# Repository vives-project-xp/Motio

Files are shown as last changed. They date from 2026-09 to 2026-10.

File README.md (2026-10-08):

# Motio

*Makes motion visible.*





> Een innovatief project voor het zichtbaar en tastbaar maken van beweging,
> door meerdere bewegende elementen om te zetten in fysieke tekeningen op papier.

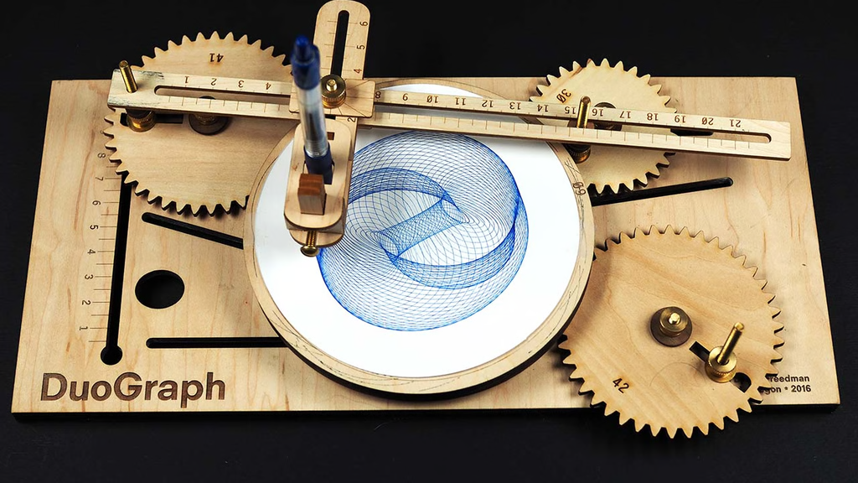
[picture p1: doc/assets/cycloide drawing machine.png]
cycloide drawing machine


## Inhoudsopgave

- [Motio](#motio)
  - [Inhoudsopgave](#inhoudsopgave)
  - [Projectoverzicht](#projectoverzicht)
  - [Functies](#functies)
  - [Technologie](#technologie)
    - [Hardware](#hardware)
    - [Software](#software)
  - [Project Structuur](#project-structuur)
  - [Simulators](#simulators)
    - [Beginposter](#beginposter)
  - [Team](#team)
  - [Academische Context](#academische-context)

## Projectoverzicht

Het Motio project is een initiatief ontwikkeld door 2de- en 3dejaars bachelorstudenten Elektronica-ICT van VIVES voor het vak Project Experience. Ons doel is het creëren van een systeem dat bewegingen tastbaar en zichtbaar maakt door ze om te zetten in fysieke tekeningen.

Het systeem combineert de beweging van meerdere elementen om complexe patronen te genereren. Een tekeninstrument vertaalt deze gecombineerde beweging naar lijnen op papier. Door parameters zoals snelheid, richting, fase en bewegingsverhouding te variëren, ontstaan telkens andere visuele patronen. Op die manier wordt de onderliggende beweging niet alleen geregistreerd, maar ook fysiek vastgelegd.

## Functies

- **Instelbare parameters:** snelheden, richtingen en fase zijn makkelijk regelbaar.
- **Visualisatie:** de beweging wordt gevisualiseerd door een tekeninstrument dat lijnen op papier maakt.
- **Preview:** indien mogelijk wordt de ingestelde beweging weergegeven op een scherm.
- **Modulaire opbouw:** gescheiden hardware- en softwarecomponenten voor eenvoudige uitbreiding.

## Technologie

### Hardware

- Stappenmotoren met dedicated drivers voor precisie-aansturing.
- Tekeninstrument als uitvoer naar papier.
- Raspberry Pi als besturingsplatform (zie [schermkeuzes](Research/Scherm/Scherm_gegevens.md) en [motor-aansturing](Research/Stappenmotoren/Stappenmotor_aansturing.md)).

### Software

- MOTIO SIMV4 in een zelfstandige map, met SIMV3 als behouden werkende basis.
- Parameterbesturing voor snelheid, richting, fase en bewegingsverhouding.

## Project Structuur

```bash
Motio/
├── doc/              # Projectdocumentatie en de projectcanvas
├── Hardware/         # Hardware van het project
├── Materiaal/        # Materiaallijst en benodigdheden
├── Research/         # Onderzoek en keuzes (scherm, stappenmotor-aansturing)
├── Software/         # Softwarecomponenten van het project
├── Software/WARD-SIM/ # Interactieve simulators
│   ├── SIMV1/        # Oorspronkelijke live simulator
│   ├── SIMV2/        # Virtueel prototype met machinebediening
│   ├── SIMV3/        # Behouden werkende basis met drie motoren, 2D/3D en BOM
│   └── SIMV4/        # Compacte box 358 × 404 × 108 mm en instelbare zichtbaarheid
└── README.md         # Dit bestand
```

## Simulators

- [SIMV1](Software/WARD-SIM/SIMV1/index.html): oorspronkelijke live simulator.
- [SIMV2](Software/WARD-SIM/SIMV2/index.html): virtueel prototype met machinebediening, mechanische transmissies en engineeringweergave. Zie de [SIMV2-handleiding](Software/WARD-SIM/SIMV2/README.md).
- [MOTIO SIMV3](Software/WARD-SIM/SIMV3/index.html): behouden werkende basis met rond papier Ø210 mm, veilige tekenzone Ø190 mm, drie SY42STH38-1684A-motoren en 2D/3D-interface. Zie [ontwerp en controles](Software/WARD-SIM/SIMV3/README.md).
- [MOTIO SIMV4](Software/WARD-SIM/SIMV4/index.html): huidige simulator met compacte opstelling, box 358 × 404 × 108 mm en afzonderlijke zichtbaarheid van wanden, bodem en bovenplaat. De drie motoren en bestaande bediening blijven behouden. Zie [starten en controles](Software/WARD-SIM/SIMV4/README.md).

### Beginposter

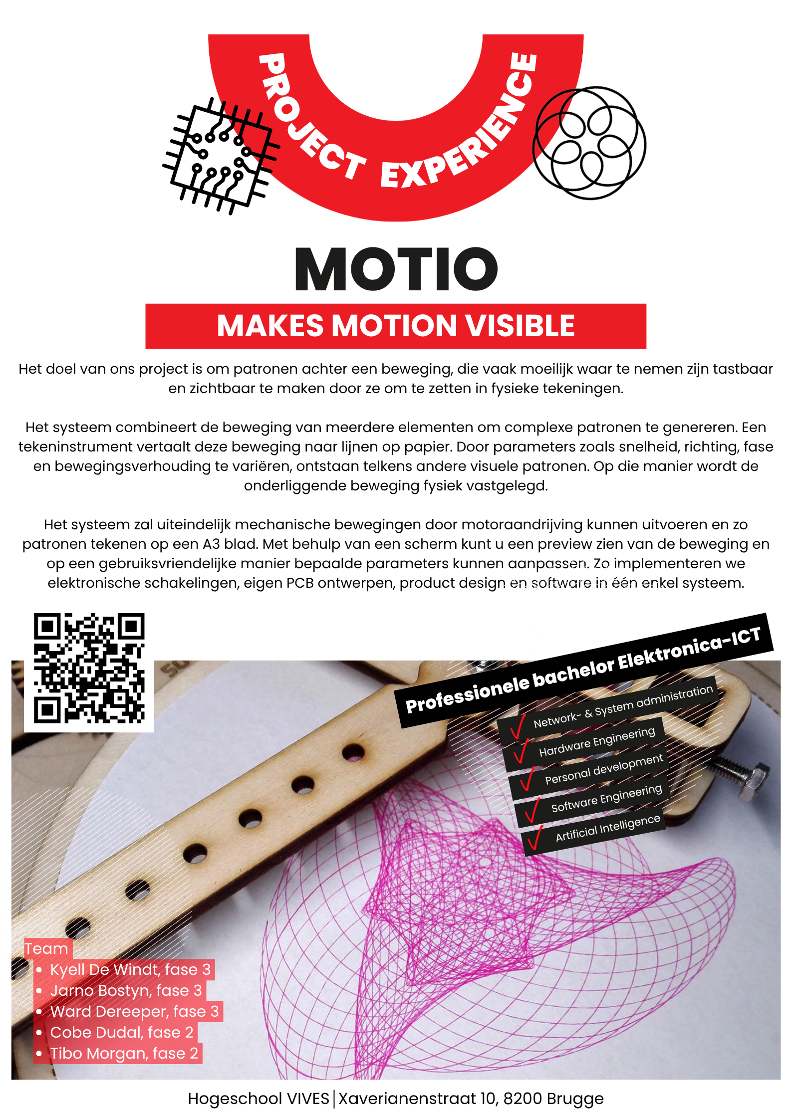
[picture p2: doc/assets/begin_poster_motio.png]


## Team

| | | |
| :---: | --- | --- |
| Kyell De Windt | Kyell De Windt | Teamlid |
| Jarno Bostyn  | Jarno Bostyn | Teamlid |
| Ward Dereeper | Ward Dereeper  | Teamlid |
|  Cobe Dudal  | Cobe Dudal | Teamlid |
| Tibo Morgan | Tibo Morgan | Teamlid |

## Academische Context

| | |
| --- | --- |
| Universiteit | VIVES Hogeschool |
| Opleiding | Bachelor Elektronica-ICT |
| Vak | Project Experience |
| Academiejaar | 2026-2027 |

Gemaakt door VIVES Bachelor Elektronica-ICT studenten.

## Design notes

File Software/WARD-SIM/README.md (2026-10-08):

# WARD-SIM

- [MOTIO SIMV4](SIMV4/index.html) - huidige simulator in een zelfstandige map: box 358 × 404 × 108 mm, compacte opstelling, drie onafhankelijke motoren en instelbare zichtbaarheid van de behuizing. Zie [starten en controles](SIMV4/README.md).
- [MOTIO SIMV3](SIMV3/index.html) - behouden werkende basis met rond papier Ø210 mm, drie motoren en 2D/3D-interface. Zie [ontwerp en controles](SIMV3/README.md).
- [Sim V1](SIMV1/index.html) - oorspronkelijke live simulator (historische referentie).
- [Sim V2](SIMV2/index.html) - eerder virtueel prototype (historische referentie).

Open de gewenste `index.html` in een browser; er is geen installatie nodig.

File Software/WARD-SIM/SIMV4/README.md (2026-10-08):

# MOTIO SIMV4

SIMV4 is een zelfstandige kopie van SIMV3 met een compactere opstelling en een houten box van **358 × 404 × 108 mm** (buitenafmetingen). Alle modelmaten blijven in millimeter. SIMV3 is intact gebleven.

## Starten

Open `index.html` rechtstreeks, of voer vanuit deze map uit:

```powershell
node tests/serve.js
```

Open [SIMV4 op deze computer](http://127.0.0.1:4174/). De server deelt alleen deze SIMV4-map. Er zijn geen externe bibliotheken of installatiecommando's nodig; voor de optionele server en tests is Node.js nodig.

## Bediening

De app opent in **Mechanical Design → 3D**. De vier afzonderlijke zijwanden en de bodem hebben elk een zichtbaarheidsschakelaar. De bovenplaat kan ondoorzichtig, semi-transparant of transparant worden weergegeven. Deze instellingen veranderen alleen de weergave; ze veranderen geen motorstand, beweging, tekening of machineconfiguratie.

De box en plaatsing volgen de meegeleverde visuele referentie. **A, B en C houden ieder een eigen motor en een eigen tandwielpaar.** Er zijn geen tandwielverbindingen tussen de drie aandrijvingen. A en B bedienen de twee penarmen; C draait het ronde papier. De draaipunten, armlengtes, motorbeugels en asdoorvoeren zijn aan de compactere box aangepast. De uiteinden van beide armen komen bij dezelfde penas samen.

De krukken blijven 65 mm; de penarmen zijn nu 180 / 160 mm. Het papier blijft Ø210 mm met een veilige tekenradius van 95 mm. De eigen tandwielparen liggen onder de bovenplaat en zijn zichtbaar te maken via de behuizingsbediening. De bovenplaat en bodem zijn 8 mm dik; de vier zijwanden zijn 8 mm dik. De hoogte van 108 mm is de buitenhoogte van de box, zonder het mechanisme erboven.

Alle bestaande SIMV3-bedieningen blijven beschikbaar: vier tabbladen, 2D/3D, camera draaien/verplaatsen/zoomen en boven-/zij-/isometrisch aanzicht, patronen en woordgenerator, afzonderlijke motorsnelheden/richtingen/fasen, configuratie, validatie en SVG-/CSV-export.

Om te tekenen: kies in **Simulator** een patroon, druk **Power on → Home → Play**. A/B bepalen de penpositie en C draait het papier. De penhoogte blijft handmatig vastgezet. **Pause** en **Stop** remmen af; **Play** hervat. **Reset → Home** begint opnieuw. Home zonder Reset kan een terugkeerlijn achterlaten. De snelheidsregelaar versnelt alleen de simulatietijd. Bij **Eigen motorinstellingen** zijn de drie motorsnelheden en richtingen afzonderlijk instelbaar.

Technische configuratiewijzigingen resetten de beweging en testgegevens. Configuratie staat centraal in `js/machineGeometry.js`; kinematica, controles, 2D/3D en BOM gebruiken dezelfde configuratie. Alleen de weergave schakelen laat de lopende simulatie ongemoeid.

## Controles en exports

Voer vanuit deze map uit:

```powershell
node tests/logic.test.js
node tests/integration.test.js
node tests/patterns.test.js
node tests/export.js
```

De regressiecontroles toetsen de FK/IK/Jacobiaan-berekeningen, onafhankelijke A/B/C-aandrijving, papiercoördinaten, bereik en vrijloop, motorlastmodel, foutstops en afremmen. De integratiecontrole gebruikt DOM/canvas-testdoubles voor de bestaande bediening, camera's en behuizingsschakelaars. De patroontest doorloopt alle bestaande patronen en letter-/woordgevallen op de live stapgrootte van 10 ms, inclusief pauzeren/hervatten. Echte WebGL en de zichtbare opstelling worden aanvullend in de browser bekeken.

`tests/export.js` genereert de mechanische SVG, doorsnede, pendetail en vijfkoloms BOM-CSV in `exports/`, met de SIMV4-configuratie.

De simulatie behoudt de bestaande geometrische veiligheidscontroles en geschatte motorbelasting. De afgelezen motorcurve bewijst het werkelijke gedrag bij lage RPM niet; drivercondities, belasting, spelingen en toleranties moeten op het fysieke prototype worden bevestigd. De tekeningen zijn een simulatie en geen productie-CAD.

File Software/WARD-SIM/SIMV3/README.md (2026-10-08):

# MOTIO V4 - mechanische simulator

V4 verfijnt de bestaande code in `SIMV3/`. De bestaande kinematica, WebGL-weergave en centrale configuratie blijven behouden. Geen installatie of externe runtimebibliotheken nodig.

Open `index.html` rechtstreeks, of start vanuit de repository:

```powershell
node Software/WARD-SIM/SIMV3/tests/serve.js
```

Open http://127.0.0.1:4173/SIMV3/.

## Bediening

Kies een patroon → Power on → Home → Play. De scrollbare lijst bevat dertien berekende voorbeeldafbeeldingen: cirkel, drie bloemen, golfring, twee eenvoudige rozetten, vier complexere verweven rozetten, spiraal en VIVES. Het volledige verwachte resultaat staat licht op het papier; de echte tekenlijn verschijnt donker en gebruikt onafhankelijk de bestaande voorwaartse kinematica. Voorbeeld tonen kan worden uitgeschakeld. A/B bepalen samen de penpositie; C draait het papier. Bij Eigen motorinstellingen gelden de invoersnelheden en richtingen voor de krukken en het papier. De live motorwaarden zijn de echte motoraswaarden: tegengesteld en vermenigvuldigd met de reductie. Positieve rotatie is met de klok mee in bovenaanzicht (+Y naar beneden).

De penhoogte wordt handmatig vastgezet. Home en afremmen tekenen ook. Pause/Stop remmen het ingestelde profiel af; een foutstop houdt de laatste toegestane pose vast. Dit is een virtuele interlock, geen garantie dat een echte machine instantaan kan stoppen. De geselecteerde patronen bewegen de pen over de al bewezen radiale route terwijl het papier draait. De twaalf geometrische figuren blijven binnen radius 81,7 mm; VIVES blijft binnen 82,7 mm en stoppen wanneer het volledige voorbeeld is getekend. De standaardbloem met vijf blaadjes duurt circa 36 simulatieseconden (circa 7 seconden bij 5×). Pause/Stop remmen op dezelfde curve af; Play hervat. Reset → Home begint een nieuwe tekening zonder het eerdere spoor. Home zonder Reset kan een terugkeerlijn achterlaten omdat de pen vast op het papier blijft. Willekeurige profielen hoeven niet volledig veilig te zijn: verboden standen worden geblokkeerd.

VIVES is een vaste lijntekening, geen algemene tekstgenerator. Afgeronde bubbelcontouren worden onderaan vloeiend verbonden met Catmull-Rom-curven, zonder de pen op te tillen of bij iedere knoop te stoppen. A/B blijven op de bewezen radiale route en C draait in beide richtingen: `r = hypot(x,y)` en `papierhoek = routehoek − atan2(y,x)`. De letterlijn ligt boven het papiercentrum zodat de papierhoek nergens onbepaald is. Het woord duurt circa 97 simulatieseconden bij 1×, circa 19 seconden bij 5×. Het profieltempo is 0,64 patroonrondes per minuut; de actuele A/B/C-snelheden variëren en worden door de bestaande limieten bewaakt.

1× gebruikt de werkelijke ingestelde bewegingssnelheid; de schuifregelaar versnelt alleen de simulatietijd. De geometrische patronen tekenen 1,5–4× sneller dan het vorige tempo: bloemen en de drie dichte rozetten 2×, golfring 1,5×, eenvoudige rozetten en de open rozet 3×, cirkel en spiraal 4×. De vier complexe figuren duren nu circa 7 min 33 s, 1 min 43 s, 6 min 43 s en 7 min 33 s bij 1×. Snelheids- en versnellingslimieten blijven ongewijzigd. De voorlopige uitgangslimieten zijn A/B 8 RPM en 1 rad/s², C 16 RPM en 3 rad/s². Bij VIVES op het nieuwe tempo geeft het model circa 8,8 / 4,8 / 51 motor-RPM als pieksnelheden en circa 0,06 Nm benodigd motorkoppel, met de huidige geometrie en belastingaannames. Dit zijn berekende startinstellingen voor een stroomgeregelde driver op 24 V en 1,68 A, geen gemeten maximale machinesnelheid. De drivercondities blijven onbevestigd totdat de echte opstelling is gecontroleerd.

Precies vier tabbladen: Simulator, Mechanical Design, Validation en Components / BOM. Technische instellingen zijn uitgeklapt beschikbaar. Configuratiewijzigingen resetten de beweging, tekening en testgegevens.

### Woordgenerator

Typ 1 tot 8 letters (A–Z) in de woordgenerator. Kleine letters worden hoofdletters; spaties, cijfers en leestekens worden niet geaccepteerd. Het voorbeeld reageert tijdens het typen. **Gebruik woord** zet het woord op het papier en vraagt opnieuw Home; daarna werkt de bestaande bediening. Het woord wordt bewaard als `wordText` in de centrale configuratie en kan dus mee worden geëxporteerd.

De generator gebruikt een klein ingebouwd alfabet met afgeronde contouren, smalle I en bredere M/W. Letterverhoudingen blijven behouden; de grootte en tussenruimte worden automatisch bepaald. De volledige curve blijft binnen 86% van de veilige radius. De tekst wordt horizontaal gecentreerd en boven het papiercentrum geplaatst, zodat de bestaande radiale penroute en papierrotatie kunnen worden hergebruikt. De letters en binnenlussen vormen één pad met de pen op het papier. De tekentijd volgt het aantal curvegedeelten, zodat langere woorden meer tijd krijgen. Het gevraagde woordtempo is 0,9 patroonrondes per minuut. Bij het toepassen wordt het volledige woordpad op 64 stappen per curvegedeelte doorgerekend en het tempo zo nodig verlaagd voor de bestaande pen- en motorlimieten, met 30% reserve in de berekende constante beweging. Korte woorden kunnen daardoor een lager tempo krijgen; een hogere vaste snelheid zou daar een foutstop veroorzaken. Er zijn geen externe lettertypen of extra bibliotheken nodig.

## Bouwgeometrie

| Onderdeel | Keuze |
|---|---|
| Papier en draaiplateau | Rond Ø210 mm, gecentreerd |
| Veiligheidsmarge | 10 mm; tekenradius 95 mm / diameter 190 mm |
| Krukken A/B | 65 mm h.o.h. (voorheen 40 mm) |
| Penarmen A/B | Bestaande 360 / 340 mm h.o.h. |
| Draaipunten A/B | Bestaande (550,148.5) / (210,-185) mm |
| A/B tandwielparen | 20:60 tanden; module 1,5; hartafstand 60 mm; 3:1 |
| C tandwielpaar | 20:80 tanden; module 1,5; hartafstand 75 mm; 4:1 |
| Tandprofiel | Rechte tanden, 20° drukhoek, breedte 9 mm |
| Pen | Holle joint, twee onafhankelijke armlagers, manuele M4-klem |
| Onderplaat | 605 × 605 × 8 mm; frame en steunen passen binnen dezelfde plaat |

Eén motor- en één uitgangstandwiel per aandrijving. Uitwendige tandwielen draaien tegengesteld. De involute visualisatie gebruikt bijpassende tooth/gap-fases in 2D en 3D; het profiel is geen productie-CAD. De berekende theoretische contactratio is circa 1,67 voor A/B en 1,69 voor C. Naaf, materiaal, passingen en werkelijke tandspeling nog kiezen vóór fabricage.

## Bereik en veiligheid

De pen hoeft niet alle XY-punten zelfstandig te bereiken. Een continue radiale machinepositie `P(s) = papiercentrum + s·(cos(-140°),sin(-140°))`, voor `0 ≤ s ≤ 95 mm`, bestrijkt met onafhankelijke papierrotatie iedere radius en papierhoek.

`validation.js` controleert deze route over 190 aaneengesloten intervallen van 0,5 mm. Het gebruikt exacte afstandsgrenzen tot de draaipunten, de crank/arm-driehoek voor seriële singulariteiten, begrensde elleboogverplaatsingen voor parallelle sluiting en verplaatsingsenveloppen voor vrijloop. Dit zijn intervalgrenzen voor de volledige route, geen PASS op basis van losse steekproeven.

Voor de standaardconfiguratie: seriële sinusmarge minstens 0,410; parallelle sinusmarge minstens 0,991; Jacobiaanconditie hoogstens 2,79; gemodelleerde vrijloop minstens 4,22 mm (eis 3 mm). Volledige veilige tekencirkel: PASS in dit geometrische model. Botsingen en singulariteiten: PASS op deze route, met die reikwijdte expliciet in de interface. De fysische motorcapaciteit en spelingen: NIET BEWEZEN.

De bestaande faserastertest en 20 s omkeerproef blijven op de achtergrond beschikbaar. Een raster bewijst geen globale veiligheid. De simulator weigert kritische singulariteiten, botsingen, assembly/working-branchwissels en een penpositie buiten radius 95 mm. Tekensporen staan uitsluitend in roterende papiercoördinaten; papier en spoor draaien samen in alle weergaven.

## Motorbron en berekeningen

Bron: [meegeleverde SY42STH38-1684A-datasheet](../../../Research/Datasheets/Stappenmotoren/SY42STH38-1684A.pdf).

Drie identieke motoren: 1,8° (200 volle stappen/omwenteling), 1,68 A, 2,8 V per fase, houdkoppel 0,36 Nm, as Ø5 mm, motorbreedte maximaal 42,3 mm, lengte 38 ±1 mm en vier M3-gaten op 31 ±0,2 mm. De motor wordt met een stroomgeregelde driver gevoed; 2,8 V is de nominale fasespanning, de curve gebruikt een voeding van 24 V.

De pull-out-curve is ongeveer afgelezen uit de PDF. Condities: 24 VDC, constante stroom 1,68 A, halfstap. De x-as is PPS, niet RPM: 400 pulsen/omwenteling geeft `RPM = PPS × 60 / 400`. Het getoonde curvebereik 200–5000 PPS is 30–750 RPM. Afgelezen dynamisch koppel circa 0,26 Nm bij 30 RPM, oplopend naar circa 0,30 Nm bij 105 RPM en aflopend naar circa 0,19 Nm bij 750 RPM. Er wordt geen curve buiten dit bereik geëxtrapoleerd en geen houdkoppel als dynamisch koppel gebruikt.

Bij de patroonprofielen wisselen A/B van snelheid en richting; C draait bij de standaardbloem op maximaal 7,2 motor-RPM. De lage motorsnelheden liggen buiten het gepubliceerde curvebereik. Daarom blijft dynamische capaciteit daar niet aangetoond. Bij VIVES bereikt C circa 51 motor-RPM, binnen het curvebereik, maar ook dit patroon passeert lagere snelheden en stilstand. Ook binnen het curvebereik moet de gebruiker drivercondities bevestigen (`motorCurveConditionsConfirmed`) voordat een curvevergelijking als onderbouwd geldt. Een eigen gemeten curve kan via het bestaande `motorCurves`-veld, met bron, oplopende `[RPM,Nm]`-punten en `conditionsConfirmed:true`, worden ingevoerd. Werkelijke belastingmetingen blijven nodig.

Volle motorstappen per uitgangsomwenteling: A/B 600, C 800. In halfstap zijn dit 1200 / 1600 pulsen. Het bestaande gekoppelde lastmodel gebruikt penlast, arm-/krukmassa, inertie, wrijving, versnelling en rendement; het is een schatting. Aangenomen: penwrijving 2 N, pendruk 2 N, aluminium E=69000 N/mm²/dichtheid 2700 kg/m³, efficiëntie 85%, draaiende massa 0,45 kg en geschatte rotor-/tandwielinertie. Alleen de Ø210×4 mm aluminiumplaat weegt circa 0,374 kg; 0,45 kg omvat een voorlopige flens-/papierbijdrage. Deze aannames komen niet uit de motorcurve.

## Centrale bestanden en controles

`machineGeometry.js` bevat de centrale configuratie en gedeelde constructievolumes. Kinematica, papiertransformatie, collision checking, motorberekeningen, 2D/3D, Validation en BOM gebruiken dezelfde configuratiesnapshot. `motorAnalysis.js` bevat alleen de afgelezen broncurve, met het bestaande configuratieveld voor eigen curves. `patterns.js` bevat acht eenvoudige figuren, vier complexere verweven rozetten en één vaste letterlijn met hun voorbeelden; het geselecteerde `patternId` staat in dezelfde centrale configuratie. De beginhoeken worden uit inverse kinematica bepaald. De bestaande simulator berekent de daadwerkelijke penpositie, snelheid, versnelling en veiligheidscontroles.

```powershell
node Software/WARD-SIM/SIMV3/tests/logic.test.js
node Software/WARD-SIM/SIMV3/tests/integration.test.js
node Software/WARD-SIM/SIMV3/tests/patterns.test.js
node Software/WARD-SIM/SIMV3/tests/export.js
```

De tests controleren 5184 FK/IK/Jacobiaanstanden, tandwielhartafstanden en rotatierichting, ronde grenzen, het continue bereikbewijs en onafhankelijke papiercoördinaten, collision-fixtures, lastmodel, motorcurvecondities, handmatige penhoogte, behoud van de laatste geldige pose, afremmen, centrale configuratiedoorwerking, vier tabs, vijf controles en vijfkoloms CSV. De patroontest voert alle dertien profielen en 33 letter-/woordgevallen volledig uit op de live stapgrootte van 10 ms. Hij controleert pauzeren/hervatten, volledige voltooiing zonder foutstop, reserves in motor-RPM en versnelling, minstens factor 2 koppelreserve waar de gepubliceerde curve geldig is, de overeenkomst tussen FK en het onafhankelijke voorbeeld, de veilige grens en de compactere plaat. Koppel buiten het gepubliceerde RPM-bereik blijft niet aangetoond; drivercondities en werkelijke belasting moeten op de machine worden bevestigd. DOM/canvas-testdoubles worden aangevuld met visuele browsercontrole van echte WebGL en de interface.

`exports/` bevat V4-SVG-tekeningen en de vijfkoloms BOM-CSV. Sim V1/V2 blijven historische versies.

Nog te bevestigen aan het prototype: driver/voeding, motorlast bij lage RPM, tandflankspeling, lager-/aspassingen, toleranties, papierloop, schroef- en naafdetails. Het envelopmodel bevat niet alle bevestigingskoppen en kabels. Het geometrische bereikbewijs is geen fysieke bouwvrijgave.

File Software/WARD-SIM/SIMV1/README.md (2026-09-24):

# MOTIO Live Simulator V1

Een lokale, dependency-vrije browserapp die de gekoppelde beweging van één driver, een roterend A3-blad en twee extern gemonteerde tekenarmen live simuleert.

## Starten

Open `index.html` rechtstreeks in een recente versie van Chrome, Edge of Firefox. Er is geen installatie, build-stap of backend nodig.

## V1-mechanisme

**ASSUMPTION V1:** de driver stuurt drie onafhankelijke uitgangen aan. De eerste roteert het A3-papier rond zijn centrum. Arm A wordt door een excentrische kruk rechts buiten het blad aangedreven; Arm B door een tweede excentrische kruk boven het blad. Beide stijve armen ontmoeten elkaar in één penwagen. De penpositie wordt exact berekend als het geometrische snijpunt van twee cirkels rond de actuele krukpennen. Geen enkel draaipunt of geleiding is aan het papier bevestigd.

Voor een direct tandwielpaar geldt `ratio = -driver_teeth / output_teeth`. De pen wordt eerst in wereldcoördinaten berekend. Daarna wordt de inverse papierrotatie toegepast en wordt het spoor in lokale A3-coördinaten opgeslagen. Daardoor draait het getekende spoor in Machine View correct mee met het papier en blijft het in Paper View vast staan.

## Aanbevolen eerste test

1. Gebruik `Dual arm test · 20 / 60 / 37 / 53`.
2. Klik **Play** en bekijk beide views.
3. Klik **Pause**.
4. Wijzig Arm A teeth van `37` naar `41` (de simulatie reset automatisch).
5. Klik **Play** en vergelijk het nieuwe patroon en de exacte repeat-periode.

## Bestanden

- `index.html` — interface en semantische structuur
- `style.css` — responsieve technische vormgeving
- `js/math.js` — breuken, GGD/KGV en coördinatentransformaties
- `js/simulation.js` — tandwielen, tijdstap, kinematica en trace
- `js/renderers.js` — Machine View en Paper View
- `js/ui.js` — controls en live datapanel
- `js/app.js` — vaste simulation timestep en renderloop
- `tests/logic.test.js` — automatische tests voor ratios, transformaties en live trace

De scripts worden bewust als gewone lokale scripts geladen (niet als ES-modules), zodat de app ook via een `file:///`-adres werkt en geen lokale webserver vereist.

Optioneel kan de logica worden gecontroleerd met `node tests/logic.test.js`.

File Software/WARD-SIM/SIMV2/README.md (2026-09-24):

# MOTIO — SIMV2

Virtueel prototype, doorontwikkeld uit SIMV1. Open `index.html` rechtstreeks in een browser; geen installatie nodig.

## Bediening

1. **Power on → Home**. De gekoppelde assen keren in een geïdealiseerde referentieroutine terug naar nul. De ingestelde krukfasen blijven behouden.
2. **Pen down → Play**. Machine View toont de machine; Paper View toont het vaste A3-papierbeeld.
3. **Pause** behoudt de positie. **Stop** stopt op de actuele positie en heft de pen. **Reset** wist het spoor, reset de simulatie en vereist opnieuw Home.
4. Gear-, fase-, geometrie- en richtingswijzigingen resetten de tekening en vereisen Home. Simulation speed verandert alleen de afspeelsnelheid.
5. Engineering overlay toont steekcirkels, krukbanen, toerentallen, coördinaten en referentiekaders.

## ASSUMPTION FOR V1 — mechanische architectuur

Eén motor drijft een centrale as met drie gelijke tandriempoelies. Drie afzonderlijke 1:1 riemtrappen op verschillende hoogtes koppelen die as aan gelijke driver-pinions. Elke pinion grijpt in een verwisselbaar uitgaand tandwiel: papier, Arm A of Arm B. Alle assen staan in lagerblokken; de pinionposities verschuiven met de tandenaantallen. Riemlengtes en spanning moeten na wisselen mechanisch worden aangepast.

Module 1 mm: steekstraal = tanden / 2 mm; hartafstand = (driver + uitgang) / 2 mm. De getekende tanden zijn schematisch, geen productieklare involuutprofielen. Het papierwiel zit coaxiaal onder het platform; een gelabelde doorsnede toont dit verborgen tandwielpaar. Stippellijnen zijn onderliggende riemtrajecten, geen losse actuatoren. De krukken zitten op de uitgaande assen boven de transmissies. Armen liggen in verschillende hoogtevlakken en ontmoeten elkaar in een gemeenschappelijke penhouder.

Een rond platform Ø526 mm draagt een gecentreerd A3-blad van 420 × 297 mm. Het spoor is opgeslagen in papiercoördinaten en draait in Machine View mee met het blad. De Paper View behoudt de lokale coördinaten. De marge is 20 mm. Buiten het blad of met geheven pen ontstaat geen spoor; bij hervatting begint een nieuwe lijn.

## Berekening

Driverhoek → verhouding −driverT/outputT → krukpennen → snijpunt van twee cirkels met vaste armlengtes → wereldpositie pen → inverse papierrotatie → tekening.

SIMV1's bestaande cirkelsnijpuntmodel, panelen, presets en vaste tijdstap zijn behouden. De continuïteitskeuze gebruikt nu afstand tot de vorige penpositie, zonder voorkeur die plots van tak wisselt om binnen het papier te blijven. Onbereikbare geometrie blokkeert de aandrijving.

De exacte gezamenlijke faseherhaling is het KGV van de gereduceerde ratio-noemers in driveromwentelingen. Een symmetrisch patroon kan eerder visueel herhalen. De weergegeven duur gebruikt driver-RPM, zonder versnellingsrampen. RPM verandert tijdsverloop, niet de geometrische patroonvorm; tandenaantallen, fasen, krukstralen en armlengtes veranderen die wel. Omkeren keert de doorlooprichting om.

## Scope en bron

Gebaseerd op de meegegeven masterprompt en de projectbeschrijving in de repository-README. Er was geen afzonderlijke projectbrief beschikbaar. Mechanische opbouw, module, platformdiameter, controller en sensoren zijn expliciete prototypeaannames.

Dit is ideale kinematica: geen berekening van motorvermogen, buiging, backlash, riemspanning, botsingen of toleranties. De homingroutine interpoleert de gemeenschappelijke driverfase in twee simulatieseconden naar de virtuele referentie; dit is geen firmware of realistisch begrensd motorprofiel. Sensorblokjes zijn statusindicatoren. Voor een bouwontwerp zijn hoogteverschillen, vrije ruimte en montage nog te controleren. Het spoor bewaart maximaal circa 350.000 punten en verwijdert daarna de oudste 50.000 om geheugen te begrenzen.

## Controle

`node tests/logic.test.js`

Controleert ratios, transformaties, vaste armlengtes, continuïteit, machine-interlocks, homing, penonderbrekingen, veranderde tandenaantallen, richting, faseherhaling en RPM-tijdschaling.

`node tests/integration.test.js`

Controleert de bestaande HTML-controls en rendercode met een gesimuleerd document en canvas, inclusief tekenen, onderbreken en hervatten. Dit vervangt geen visuele browsercontrole. De ingebouwde browser blokkeerde het lokale file-adres tijdens ontwikkeling, dus visuele QA is niet afgerond.

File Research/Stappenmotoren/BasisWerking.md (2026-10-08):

# Basis werking

## Wat is een stappenmotor
Een stappenmotor is een borstelloze synchrone gelijkstroommotor die digitale pulsen omzet in rotatie van een mechanische as.In tegenstelling tot veel andere standaardtypen motoren, draait een stappenmotor niet continu gedurende een bepaald aantal omwentelingen totdat de gelijkspanning die eraan wordt geleverd, wordt uitgeschakeld. Het heeft verschillende spoelen die in groepen zijn georganiseerd, de zogenaamde "fasen". Als elke fase beurtelings wordt ingeschakeld, draait de motor stap voor stap.

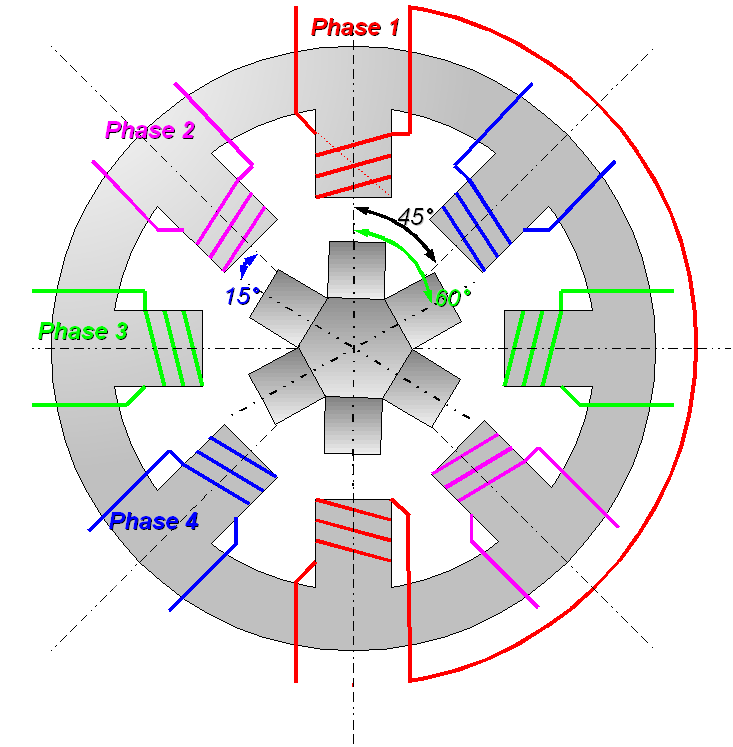
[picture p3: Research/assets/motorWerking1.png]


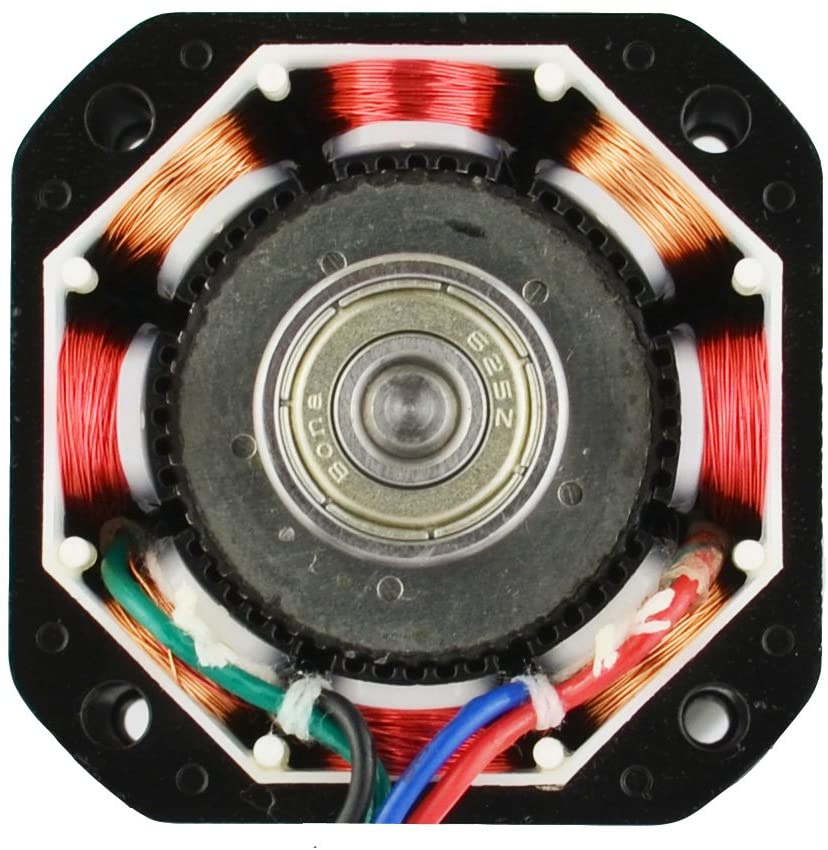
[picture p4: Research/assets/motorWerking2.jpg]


Stappenmotoren verdelen de gehele draaibeweging in meerdere gelijke stappen. Zolang de motor de juiste afmetingen heeft voor het koppel en de snelheid van de toepassing, kan de positie van de motor worden geregeld om in een van deze stappen te bewegen en daar te blijven zonder enige feedback van een positiesensor.

Bronnen:
(https://www.stepperonline.nl/stappenmotoren)
https://nl.wikipedia.org/wiki/Stappenmotor

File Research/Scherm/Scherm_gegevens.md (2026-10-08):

## Scherm
Eventuele keuzes voor het scherm bedoelt voor een Raspberry Pi:

Optie 1: https://www.kiwi-electronics.com/en/raspberry-pi-touch-display-2-7-inch-20235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

Optie 2: https://www.amazon.com/dp/B0D3QB7X4Z?tag=nerdtechy-20&th=1

Optie 3: https://eu.robotshop.com/products/7-in-capacitive-touch-screen-1024x600-hdmi

Optie 4: https://www.raspberrystore.nl/PrestaShop/nl/beeldschermen/612-raspberry-pi-touch-display-2-5056561803937.html

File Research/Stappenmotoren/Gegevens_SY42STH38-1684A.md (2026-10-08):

# Technische gegevens

## SY42STH38-1684A

Step angle: 1,8
Number of phase: 2
Rated Voltage (V): 2,8
Rated Current (A): 1,68
Resistance Per Phase (Ohm): 1,65

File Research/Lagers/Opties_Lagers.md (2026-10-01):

# Lagers
Mogelijke opties voor lagers om te bestellen.

Optie 1: https://kogelrollen.be/kogelrol-kogelpot-15875-mm-met-bevestigingsgaten/80041200-p-41200.html

Optie 2: https://www.neita.nl/webshop/lagers/overige-lagers/sps-15-b-kogelpot-15mm-300193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

Mochten de andere opties niet van toepassing zijn: https://www.amazon.com.be/-/nl/Kogellager-Draaibare-Bearing-Vierkante-Computer/dp/B099R5PK89?language=nl_BE

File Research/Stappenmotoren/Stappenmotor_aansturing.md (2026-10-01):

## Stappenmotor
Eventuele driver voor stappenmotoren: https://www.poscope.com/product/bipolar-stepper-motor-driver-postep25-256/

We hebben 2 drivers nodig.

Gegevens van motor ST42STH38-1684A: https://www.pololu.com/product/2267/pictures
Gegevens van motor Stepping Motor 42BYG-40015-22BA: https

Aansluitkabels voor stappenmotors:
https://be.farnell.com/en-BE/multicomp-pro/mp008749/cable-assy-6p-rcpt-free-end-150mm/dp/3886084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

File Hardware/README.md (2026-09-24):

# Hardware

In dit document zal alles te maken met de hardware van dit project terug te vinden zijn..

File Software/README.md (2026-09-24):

# Software

In deze map zal alles te maken met de software terug te vinden zijn.

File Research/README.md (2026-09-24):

# Research
In deze map zal het gemaakte onderzoek in verband met dit project terug te vinden zijn.

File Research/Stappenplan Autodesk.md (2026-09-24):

We werken met Fusion 360,
voor een tandwiel te tekenen in fusion 360 zit dit standaard ingebouwd zodat je de nodige waarden moet ingeven van je tandwiel en die word dan gemaakt. 
Je kan dit doen aan de hand van de mode SpurGear (we moeten deze nog aanzetten).

Hoe zet ik SpurGear aan?

1. je maakt een nieuwe part design.
2. je gaat naar utilities Utilities
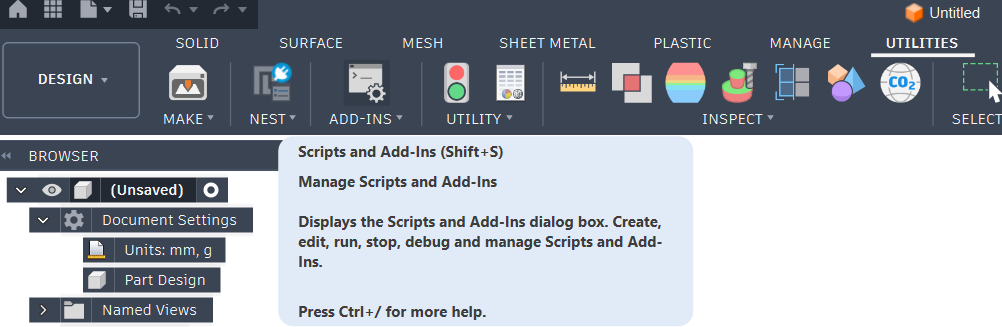
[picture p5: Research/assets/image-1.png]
ADD-INS
3. nu klik je op "ADD-INS" 
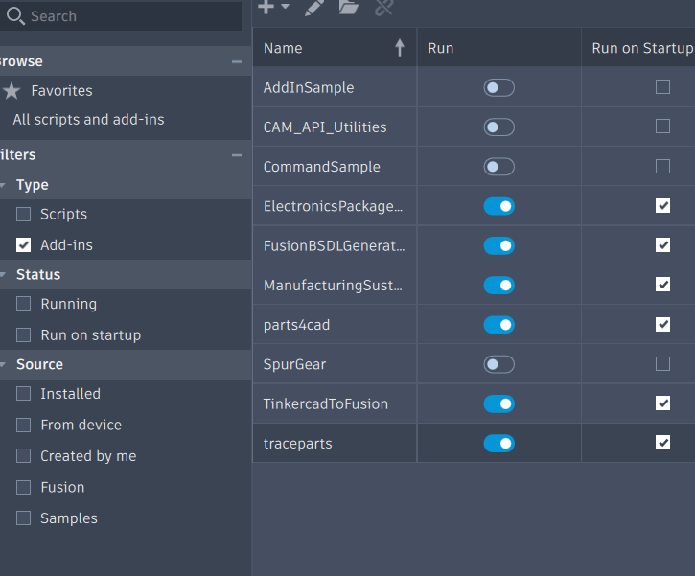
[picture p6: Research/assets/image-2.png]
SpurGear
4. nu moet je de ADD-IN  "SpurGear" aanzetten en aanvinken. 
5. Nu gaan we terug naar "Solid" Solid
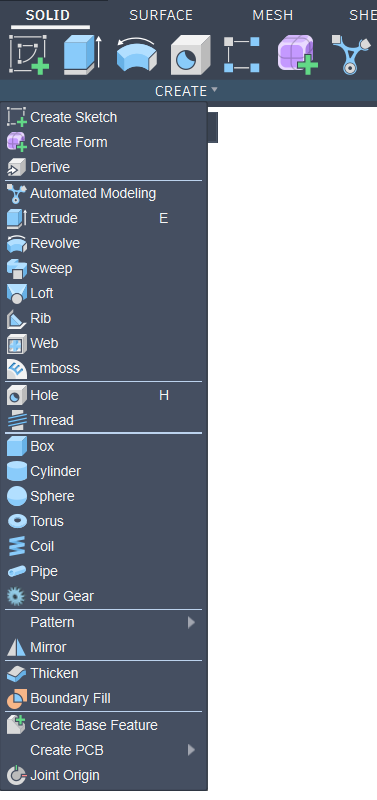
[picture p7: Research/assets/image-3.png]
Create Spurgear
6. We klikken dan op "CREATE" en dan op Spur Gear 
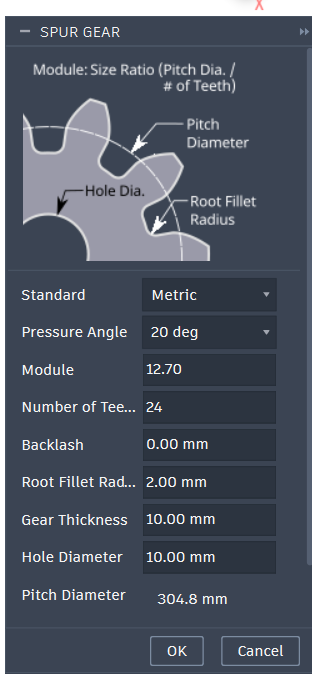
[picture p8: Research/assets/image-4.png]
Tandwiel settings
7. Je krijgt dan een venster met de nodige info die we moeten aanpassen voor een juiste tandwiel te krijgen. Hier moeten we onze eigen waarden invullen voor de nodige tandwiel. 
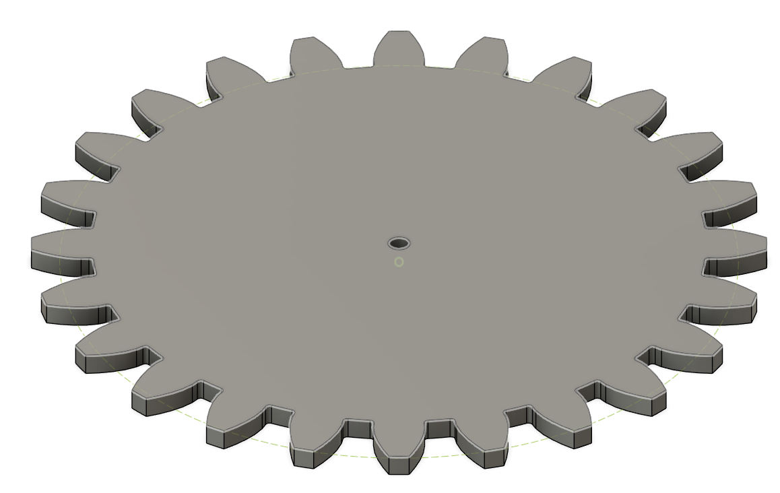
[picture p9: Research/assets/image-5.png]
resultaat tandwiel
8. Als je dan waarden hebt ingegeven dan krijd je het volgende als resultaat:

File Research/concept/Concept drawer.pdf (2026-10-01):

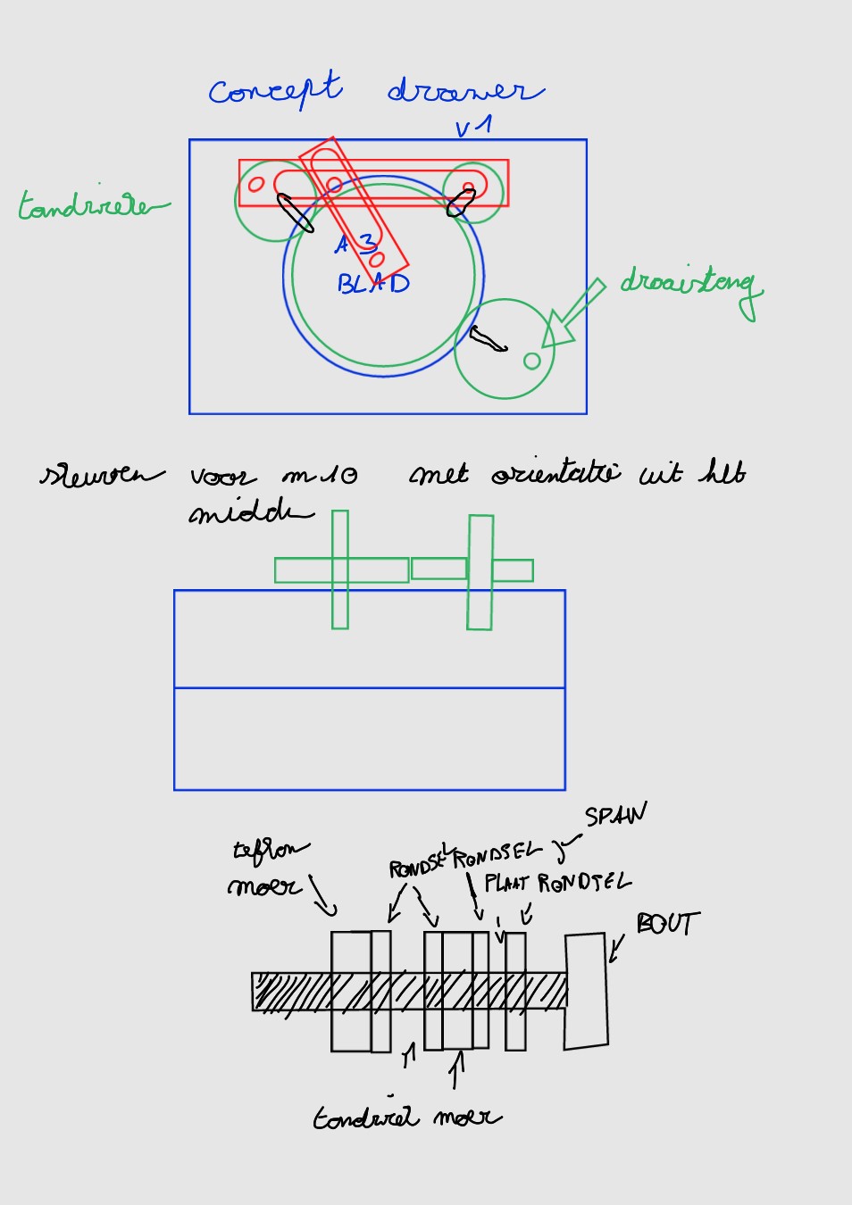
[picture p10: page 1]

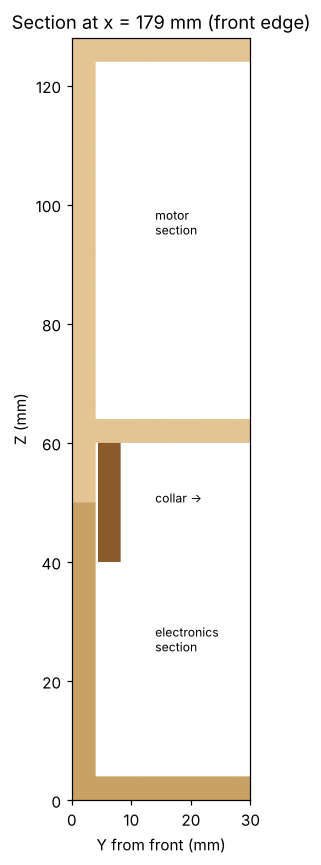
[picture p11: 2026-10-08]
Research/concept/v2/lasersnij/doorsnede_rand.png

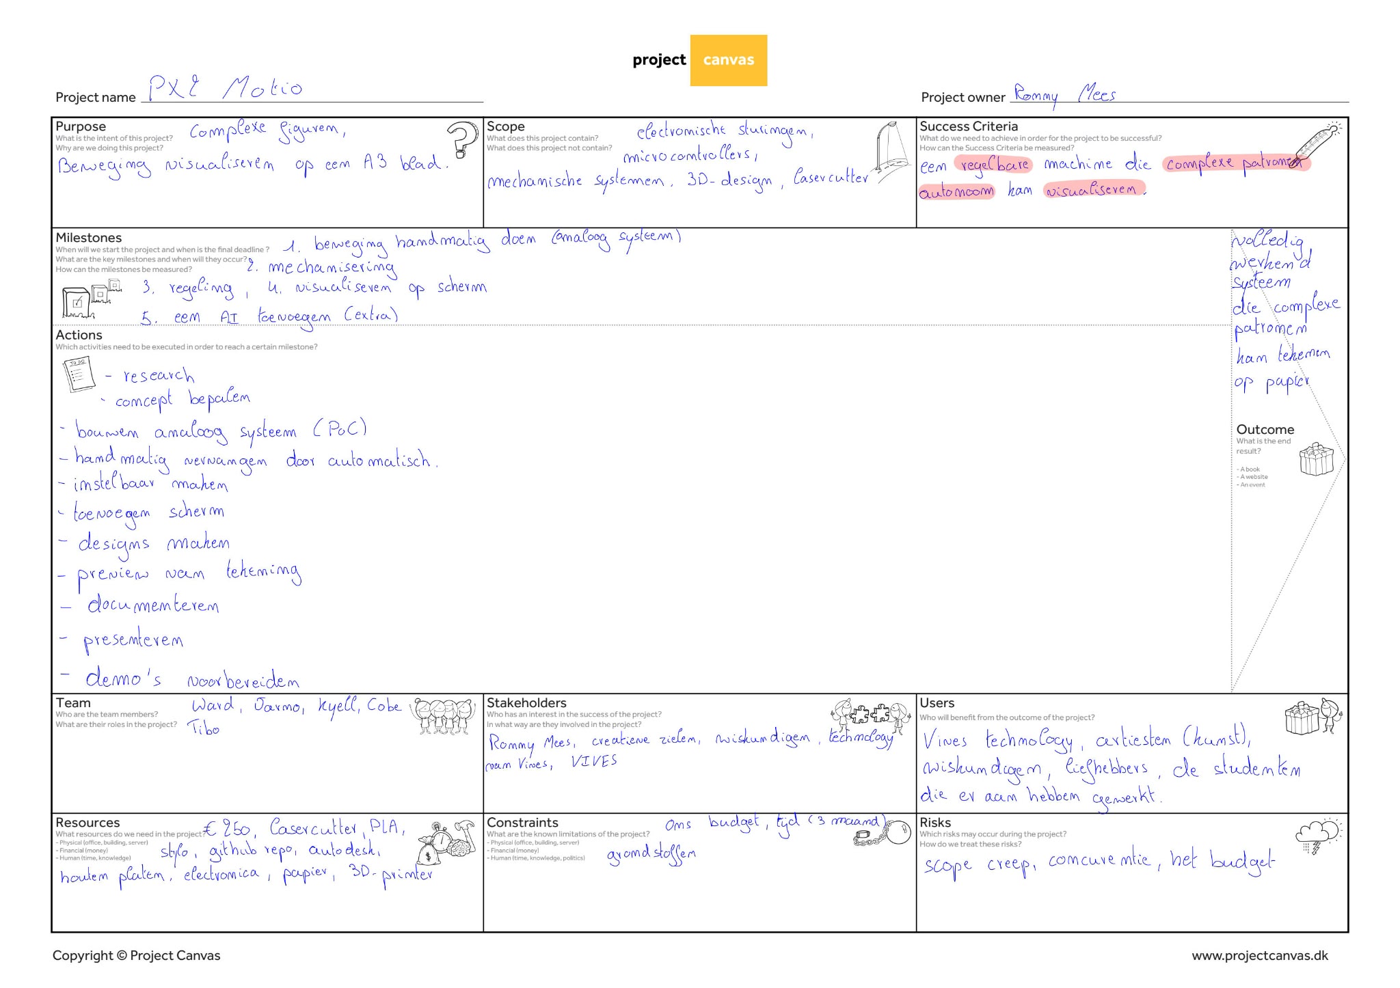
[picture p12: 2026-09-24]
doc/assets/project canvas motio.jpeg

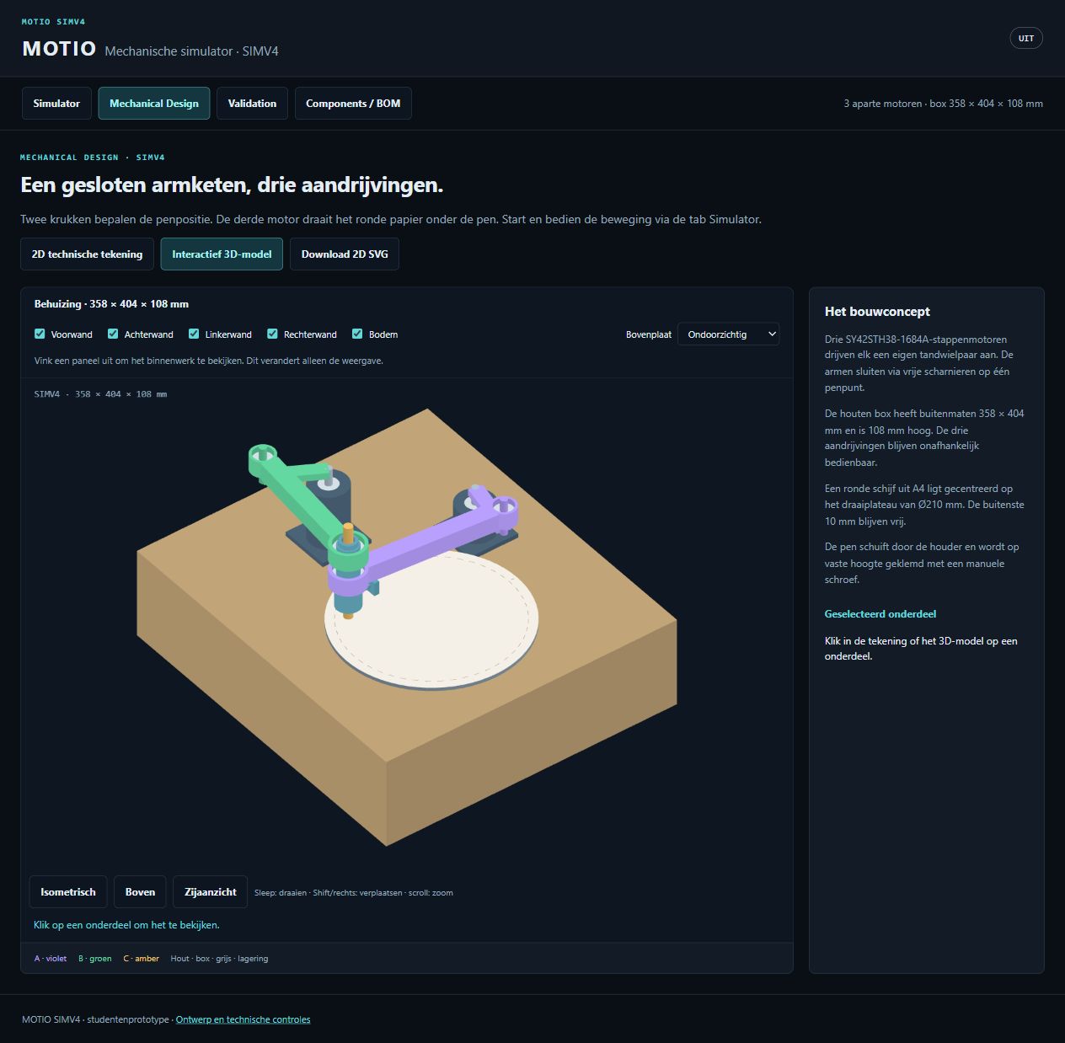
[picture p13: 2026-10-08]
Software/WARD-SIM/SIMV4/exports/SIMV4-preview.png

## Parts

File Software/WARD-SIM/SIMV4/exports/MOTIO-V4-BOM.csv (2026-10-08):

Onderdeel | Aantal | Afmetingen | Materiaal | Specificatie / opmerking
Stappenmotor A · SY42STH38-1684A | 1 | 42.3 × 42.3 × 38 mm; as Ø5 mm | Staal / koper | 1.8°; 1.68 A; 2.8 V per fase; houdkoppel 0.36 Nm. 4 × M3 op 31 mm. Dynamisch koppel: datasheetcurve bij 24 V / 1,68 A / halfstap.
Aandrijfas A | 1 | Ø8 × 98 mm | Staal | Schouderas met borging; lagerpassingen nog vastleggen.
Lagersteun A | 1 | Ø44 mm; lagerafstand 32 mm | Aluminium | Eén lager lokaliseert axiaal; tweede buitenring kan axiaal schuiven.
Uitgangstandwiel A | 1 | 60 tanden; module 1.5; steek Ø90 × 9 mm; boring Ø8 | Nog kiezen | Rechte tanden, 20° drukhoek; reductie 3:1; hartafstand 60 mm. Motor en uitgang draaien tegengesteld. Naaf en materiaal vóór bouw kiezen.
Kruk A | 1 | 65 mm h.o.h. × 16 × 8 mm | Aluminium | Klemnaaf Ø8; elleboogscharnier Ø8.
Penarm A | 1 | 180 mm h.o.h.; koker 20 × 20 × 1.5 mm | Aluminium | Met eindstukken en vrije scharnieren; armlaag z84 mm.
Stappenmotor B · SY42STH38-1684A | 1 | 42.3 × 42.3 × 38 mm; as Ø5 mm | Staal / koper | 1.8°; 1.68 A; 2.8 V per fase; houdkoppel 0.36 Nm. 4 × M3 op 31 mm. Dynamisch koppel: datasheetcurve bij 24 V / 1,68 A / halfstap.
Aandrijfas B | 1 | Ø8 × 130 mm | Staal | Schouderas met borging; lagerpassingen nog vastleggen.
Lagersteun B | 1 | Ø44 mm; lagerafstand 32 mm | Aluminium | Eén lager lokaliseert axiaal; tweede buitenring kan axiaal schuiven.
Uitgangstandwiel B | 1 | 60 tanden; module 1.5; steek Ø90 × 9 mm; boring Ø8 | Nog kiezen | Rechte tanden, 20° drukhoek; reductie 3:1; hartafstand 60 mm. Motor en uitgang draaien tegengesteld. Naaf en materiaal vóór bouw kiezen.
Kruk B | 1 | 65 mm h.o.h. × 16 × 8 mm | Aluminium | Klemnaaf Ø8; elleboogscharnier Ø8.
Penarm B | 1 | 160 mm h.o.h.; koker 20 × 20 × 1.5 mm | Aluminium | Met eindstukken en vrije scharnieren; armlaag z116 mm.
Stappenmotor C · SY42STH38-1684A | 1 | 42.3 × 42.3 × 38 mm; as Ø5 mm | Staal / koper | 1.8°; 1.68 A; 2.8 V per fase; houdkoppel 0.36 Nm. 4 × M3 op 31 mm. Dynamisch koppel: datasheetcurve bij 24 V / 1,68 A / halfstap.
Aandrijfas C | 1 | Ø12 × 95 mm | Staal | Schouderas met borging; lagerpassingen nog vastleggen.
Lagersteun C | 1 | Ø42 mm; lagerafstand 44 mm | Aluminium | Eén lager lokaliseert axiaal; tweede buitenring kan axiaal schuiven.
Uitgangstandwiel C | 1 | 80 tanden; module 1.5; steek Ø120 × 9 mm; boring Ø12 | Nog kiezen | Rechte tanden, 20° drukhoek; reductie 4:1; hartafstand 75 mm. Motor en uitgang draaien tegengesteld. Naaf en materiaal vóór bouw kiezen.
Motortandwiel | 3 | 20 tanden; module 1.5; steek Ø30 × 9 mm; boring Ø5 | Nog kiezen | Rechte tanden, 20° drukhoek; klemnaaf voor motoras.
Motorbeugel | 3 | 54 × 54 × 5 mm; 4 × M3 op 31 mm | Aluminium | Vaste bevestiging met beperkte uitlijnmogelijkheid voor tandspeling.
Groefkogellager 608-2RS | 6 | 8 × 22 × 7 mm | Lagerstaal | Vier hoofdlagers en twee ellebooglagers.
Penlager 6804 | 2 | 20 × 32 × 7 mm | Lagerstaal | Onafhankelijke armrotatie rond de holle penas. Uitvoering en passing nog kiezen.
Plateaulager 6001 | 2 | 12 × 28 × 8 mm | Lagerstaal | Twee gescheiden lagerposities op de papierspindel.
Elleboogscharnier | 2 | Schouderpost Ø8 mm; M6 borging | Staal | Schroefdraad buiten het draaiende lagervlak.
Holle penas | 1 | Ø20; boring Ø13 mm | Staal | Pen loopt door beide armlagers. Schouders en borgmoer nog detailleren.
Afstandbus en axiale borging | 1 | Ø24/20; afstandbus 25 mm | Staal | Borgt de binnenringen; één buitenring houdt axiale vrijheid.
Penhouder met manuele klemschroef | 1 | Ø28 × 22 mm; pen Ø6–12 mm | Aluminium | Handmatig vaste penhoogte; M4 klemschroef met Ø16 handknop en zachte drukpad.
Centreerbus en drukpad | 1 | Bus passend op pen; drukpad 6 × 6 × 2 mm | Nylon / TPU | Vervangbare zachte contactdelen.
Draaiplateau | 1 | Ø210 × 4 mm | Aluminium | Gecentreerde papierschijf; draaiende massa 0.45 kg is een inschatting inclusief flens.
Rond papier | 1 | Ø210 mm; veilige tekenzone Ø190 mm | Papier | Uit A4 210 × 297 mm geknipt; gecentreerd en vastgezet.
Spindelflens | 1 | Ø60 × 8 mm | Aluminium | Verbindt de plaat met de papierspindel.
Box met bodem en bovenplaat | 1 | 358 × 404 × 108 mm buitenmaat; plaat 8 mm; wand 8 mm | Multiplex | Vier zijwanden; eenvoudige asdoorvoeren in de bovenplaat. Zichtbaarheid wijzigt alleen de weergave.
Bevestigingsmateriaal | 1 | M3 / M4 / M5 / M6; aantallen bij montage bepalen | Staal | Bouten, borgmoeren en afstandsringen.

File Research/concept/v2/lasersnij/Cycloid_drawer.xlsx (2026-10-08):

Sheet: Gears
Cycloid drawer – gears on the lid
Blue = input you can change. Black = formula. Centre positions come from the generator (config.py).
Module (mm) | 3
Material thickness (mm) | 4
Backlash per tooth (mm) | 0.15
Lid width (mm) | 358
Lid depth (mm) | 408
Lid edge margin (mm) | 4
M10 hole Ø (mm) | 10.5
Gear | Teeth | Pitch Ø (mm) | Tip Ø (mm) | Root Ø (mm) | Centre X on lid (mm) | Centre Y on lid (mm) | Actual distance to turntable (mm) | Required centre distance (mm) | Mesh check | Turntable turns per gear turn | Min. clearance to lid edge (mm) | Edge check | Features
Turntable | 100 | 300.0 | 306.0 | 292.5 | 179.0 | 240.0 | – | – | – | – | 15.0 | OK | Ø10.5 axle hole; engraved paper guides Ø210 circle + 200×200 square
Left (top) | 32 | 96.0 | 102.0 | 88.5 | 69.0 | 75.4 | 198.0 | 198.0 | OK | 0.320 | 18.0 | OK | Ø10.5 axle + 2 opposite radial M10 slots, from r=20 mm outward (adjustable pin)
Right (top) | 30 | 90.0 | 96.0 | 82.5 | 289.0 | 79.0 | 195.0 | 195.0 | OK | 0.300 | 21.0 | OK | Ø10.5 axle + 2 opposite radial M10 slots, from r=20 mm outward (adjustable pin)
Crank | 20 | 60.0 | 66.0 | 52.5 | 321.0 | 350.6 | 180.0 | 180.0 | OK | 0.200 | 4.0 | OK | Ø10.5 axle + Ø6.5 hole for M6 handle bolt at r=17 mm
Non-meshing gears must stay ≥ 3 mm apart (tip to tip):
Pair | Distance between centres (mm) | Tip-to-tip gap (mm) | Check
Left ↔ Right | 220.0 | 121.0 | OK
Left ↔ Crank | 373.1 | 289.1 | OK
Right ↔ Crank | 273.5 | 192.5 | OK

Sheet: Parts
Parts list – laser-cut files (folder: concept\lasersnij)
File | Part | Qty | Material | Size (mm) | Notes
1_doos_met_asgaten.svg | Electronics section: bottom | 1 | 4 mm MDF/plywood | 358 × 408 | Finger joints on all 4 edges
1_doos_met_asgaten.svg | Electronics section: walls (front/back/left/right) | 4 | 4 mm MDF/plywood | 358 / 408 × 50 | Open top edge
1_doos_met_asgaten.svg | Collar strips (front/back/left/right) | 4 | 4 mm MDF/plywood | 349.4 / 399.4 × 20 | Glue inside the electronics section, 10 mm sticking out; 0.3 mm play per side to the motor section
1_doos_met_asgaten.svg | Motor section: walls (front/back/left/right) | 4 | 4 mm MDF/plywood | 358 / 408 × 78 | Slots 10 mm above the bottom edge for the divider; 10 mm skirt slides over the collar
1_doos_met_asgaten.svg | Motor section: divider (floor) | 1 | 4 mm MDF/plywood | 358 × 408 | Ø30 cable hole in the middle; rests on the collar
1_doos_met_asgaten.svg | Motor section: lid | 1 | 4 mm MDF/plywood | 358 × 408 | 4 × Ø10.5 axle holes
2_tandwielen.svg | Turntable gear z100 | 1 | 4 mm MDF/plywood | Ø306 tip | Carries the paper
2_tandwielen.svg | Left gear z32 | 1 | 4 mm MDF/plywood | Ø102 tip | Radial M10 slots r=20–34 mm
2_tandwielen.svg | Right gear z30 | 1 | 4 mm MDF/plywood | Ø96 tip | Radial M10 slots r=20–31 mm
2_tandwielen.svg | Crank gear z20 | 1 | 4 mm MDF/plywood | Ø66 tip | Ø6.5 hole for M6 handle at r=17 (M10 would hit the axle nut)
3_armen.svg | Cross arm (dwarsarm) | 1 | 4 mm MDF/plywood | 330 × 26 | Hole at left end, 5 attachment holes, slot 165–317 mm for the right pin
3_armen.svg | Pen arm A | 1 | 4 mm MDF/plywood | 260 × 26 | 11 × Ø10.5 holes every 20 mm, Ø12 pen hole at 245 mm
3_armen.svg | Pen arm B | 1 | 4 mm MDF/plywood | 260 × 26 | Same as pen arm A
montage_bovenaanzicht.svg / .png | Top-view assembly preview | – | – | 358 × 408 | Not for cutting
generator/ | Python generator | – | – | – | Regenerates all files; change values in config.py
 | Total laser-cut parts | 22

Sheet: Hardware
Hardware & assembly
Quantities from the Fusion 360 assembly model – blue cells can be changed.
Item | Qty | Use
M10 × 16 bolt | 2 | Turntable axle (must stay below the paper) + arm joint
M10 × 30 bolt | 4 | Axles of left, right and crank gear + left crank pin
M10 × 35 bolt | 1 | Right crank pin
M6 × 60 bolt | 1 | Crank handle
M10 nut | 12 | 4 on the lid, 3 lock nuts on the gears, 2 pin nuts, 2 on the arms, 1 on the joint
M6 nut | 2 | Handle: one on the gear, one on top of the grip
PTFE washer M10 (Ø22 × 1.5) | 7 | Under every gear, and above the 3 small gears
Spacer M10, 5.5 mm | 1 | Left pin, between pin nut and arm
Spacer M10, 9.5 mm | 1 | Right pin, between pin nut and arm
Handle grip Ø20 × 40, hole 6.5 | 1 | Sleeve on the M6 handle bolt
Axle stack, small gears (bottom → top)
1. Bolt head under the lid (bolt points up)
2. Lid (4 mm)
3. Nut on top of the lid
4. PTFE washer
5. Gear (4 mm)
6. PTFE washer
7. Lock nut (snug, not tight)
Turntable: same, but without the top washer and lock nut – it rests on its washer so nothing sticks up through the paper.

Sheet: Notes
Notes
Topic | Detail
Box | Two stacked sections, 358 × 408 × 128 mm. Bottom: electronics, 56 mm clear inside. Top: motors, 60 mm clear between divider and lid (fits NEMA17 up to 48 mm long). A collar glued in the bottom section slides 10 mm into the top section.
Paper | Rotating full A4 needs Ø364 mm and does not fit the 358 mm box. Use a Ø210 circle or 200 × 200 square cut from A4 (A4 is 210 wide).
Layer colours | Red = cut, blue = engrave, grey = text (same as the original box file).
Gear standard | Module 3, 20° pressure angle, involute teeth, 4 mm sheet.
Backlash | 0.15 mm removed per tooth for laser kerf. Test-cut a small pair first; adjust 'backlash' in the generator if too tight/loose.
Arm setup – sketch | Cross arm: hole on the left pin, slot over the right pin; pen arm attached to it.
Arm setup – classic (most reliable) | One pen arm on each gear pin, joined with one M10 bolt where they cross; pen in the Ø12 hole beyond the joint. Different holes = different patterns.
Fusion 360 | Script in concept\fusion\CycloidDrawer builds the full 3D assembly.
Status | Files generated and checked in a preview and a dry-run of the Fusion script; not yet test-cut.

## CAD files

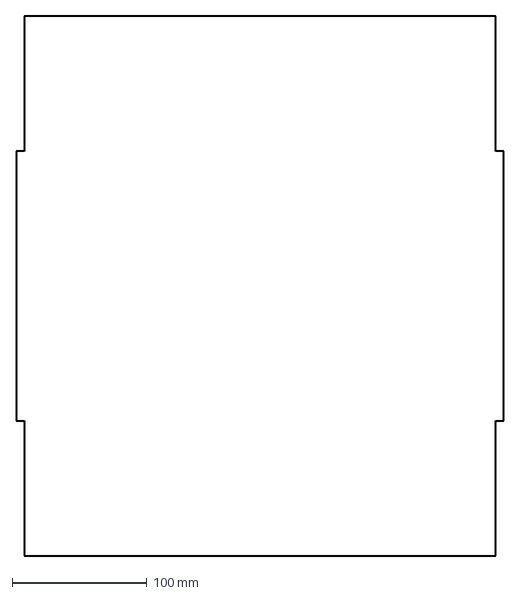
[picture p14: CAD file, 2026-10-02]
Hardware/BestandenBoxV1/mPlaat.dxf
362.0 x 400.0 mm

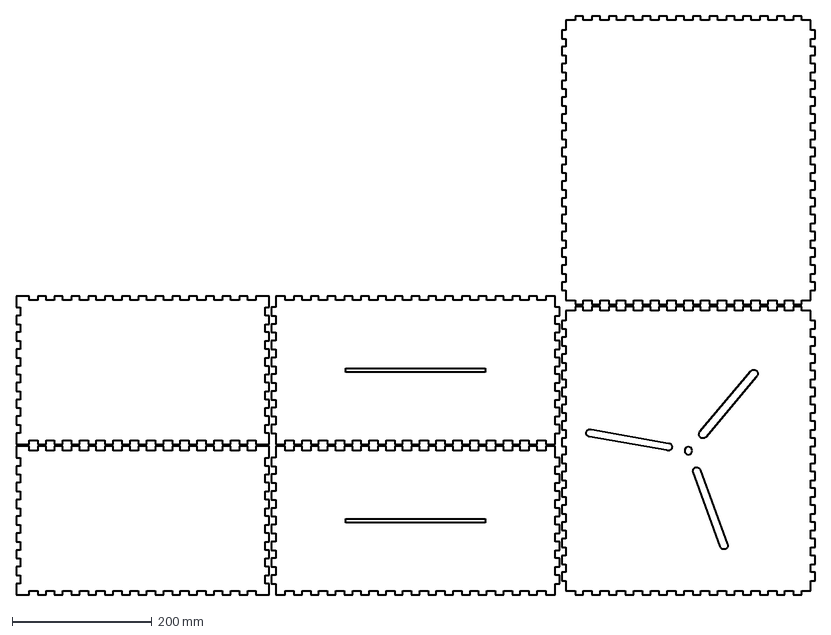
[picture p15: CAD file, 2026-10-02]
Hardware/BestandenBoxV1/MotioV1.dxf
1142.0 x 827.0 mm

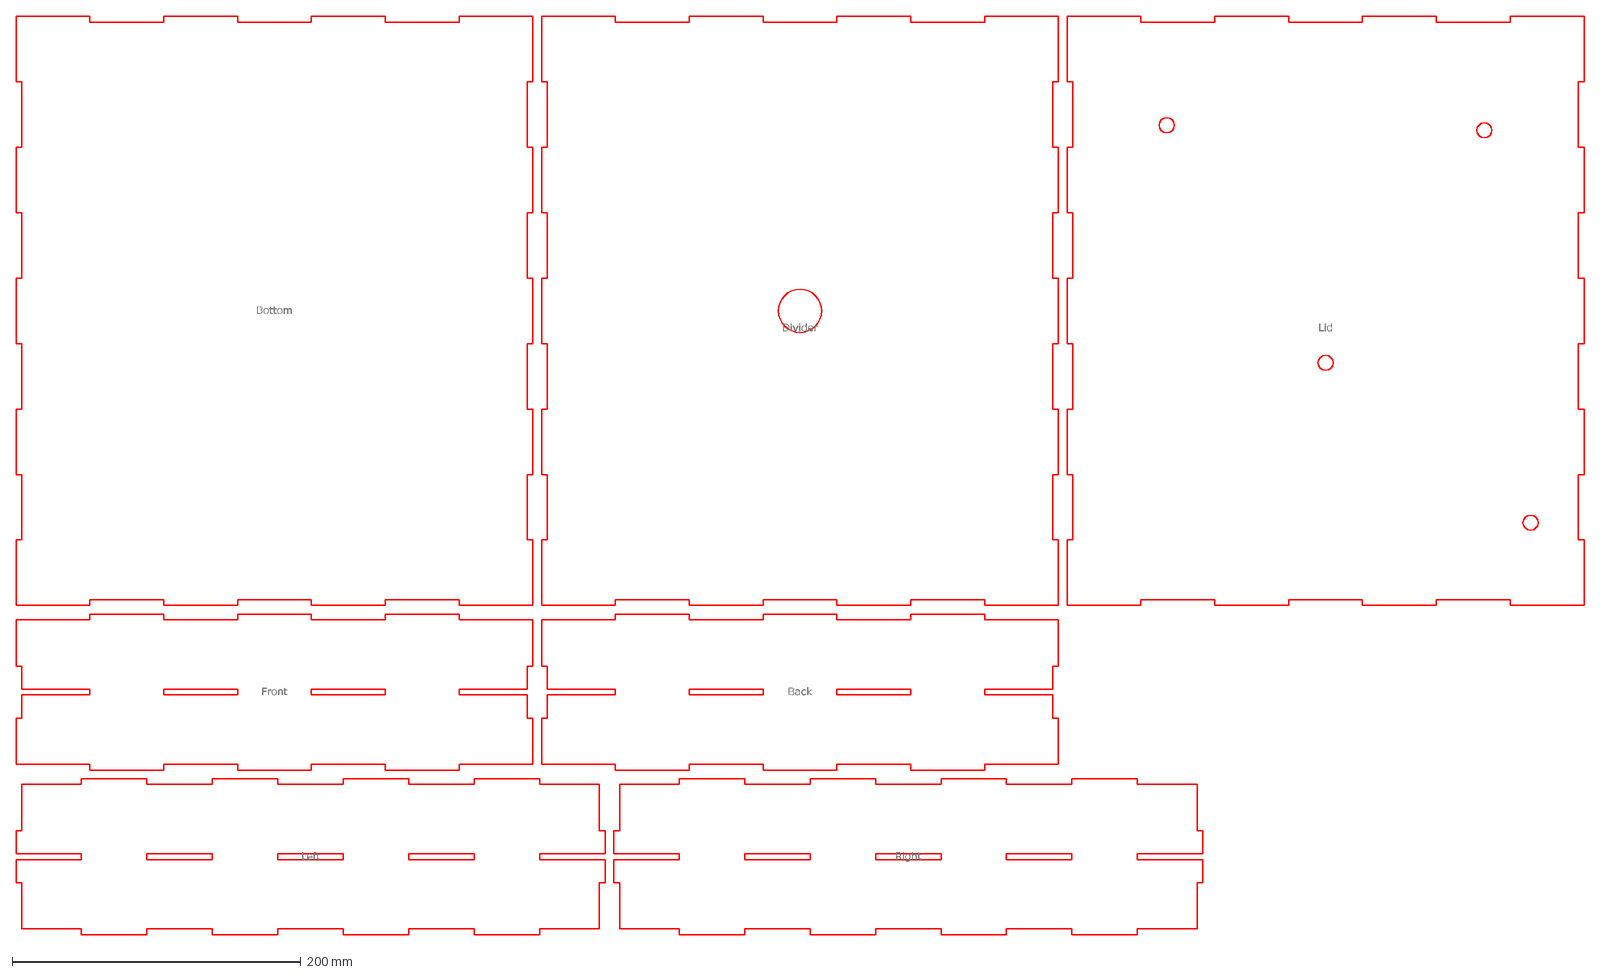
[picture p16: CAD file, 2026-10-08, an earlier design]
Research/concept/v1/lasersnij/dxf/v1 - manueel/1_doos_met_asgaten.dxf
Bottom
Divider
Lid
Front
Back
Left
Right

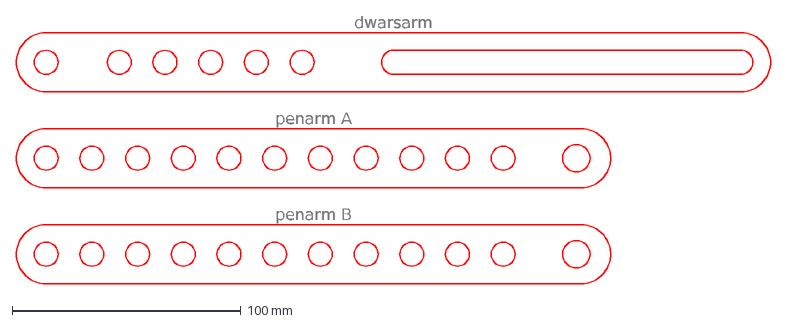
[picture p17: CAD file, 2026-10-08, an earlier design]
Research/concept/v1/lasersnij/dxf/v1 - manueel/3_armen.dxf
dwarsarm
penarm A
penarm B

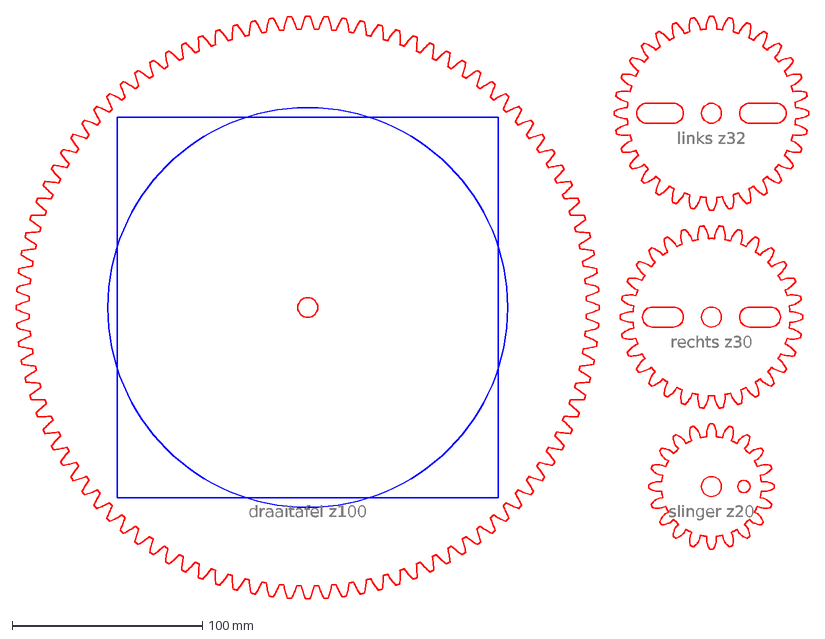
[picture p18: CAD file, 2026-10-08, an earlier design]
Research/concept/v1/lasersnij/dxf/v1 - manueel/2_tandwielen.dxf
draaitafel z100
links z32
rechts z30
slinger z20

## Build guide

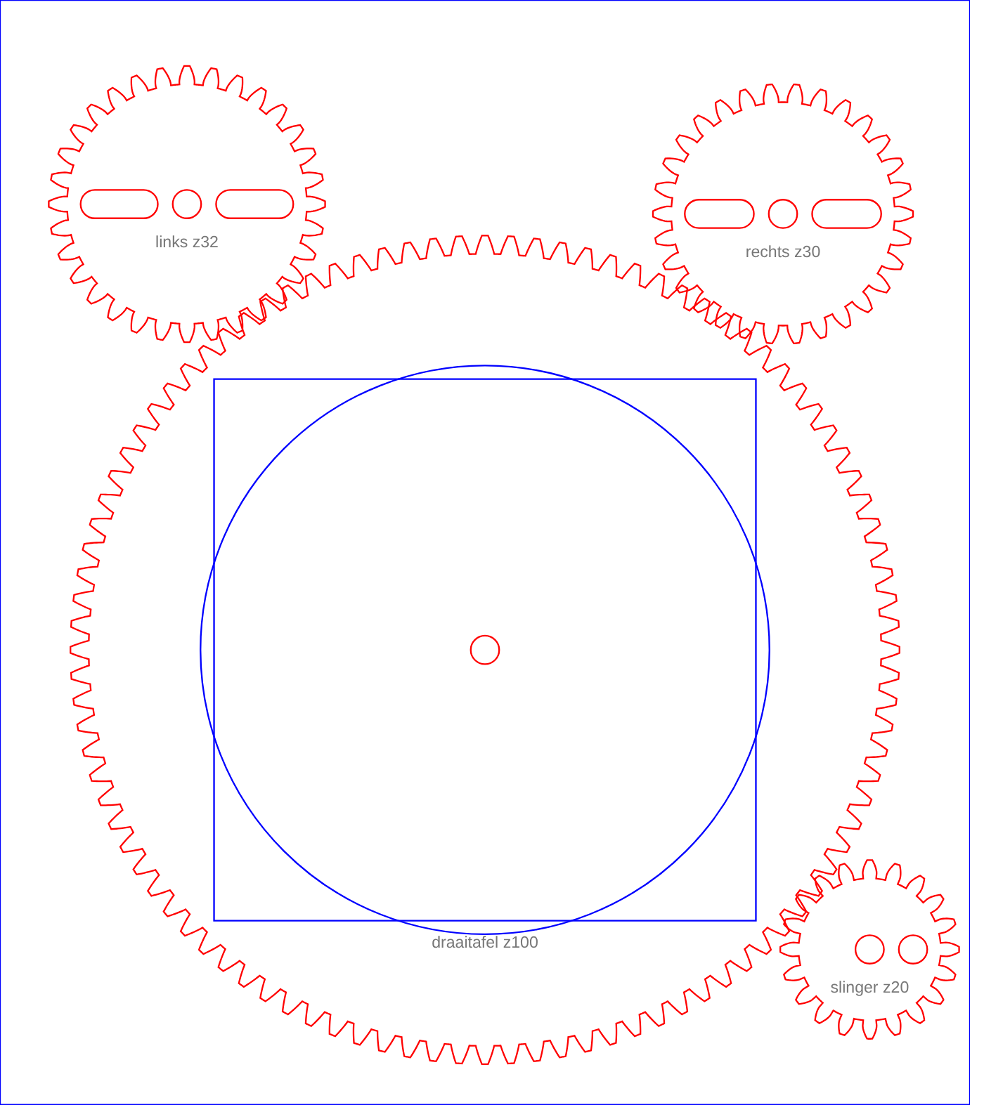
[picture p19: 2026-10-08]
Research/concept/v2/lasersnij/montage_bovenaanzicht.png

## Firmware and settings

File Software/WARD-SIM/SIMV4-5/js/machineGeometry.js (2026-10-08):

(function () {
'use strict';
// Length mm, angle rad, time s, force N, mass kg; motor calculations convert to SI.
const DEFAULT_CONFIG=Object.freeze({patternId:'flower5',wordText:'MOTIO',rpmA:.8,rpmB:-.425,rpmC:-1.8,phaseA:49.0031578912355,phaseB:154.84031330144893,phaseC:0,radiusA:65,radiusB:65,lengthA:180,lengthB:160,
 pivotAx:280,pivotAy:180,pivotBx:160,pivotBy:100,paperX:150,paperY:280,paperRadius:105,paperMargin:10,paperThickness:4,paperMass:.45,
 couplingRadius:9,couplingHeight:18,
 motorStepAngle:1.8,motorCurrent:1.68,motorVoltage:2.8,motorHoldingTorque:.36,motorWidth:42.3,motorLength:38,motorShaftDiameter:5,motorMountPitch:31,
 motorSupplyVoltage:24,motorDriveCurrent:1.68,motorStepsPerFullStep:16,motorCurveConditionsConfirmed:0,motorRadialLimit:28,motorRadialReference:20,motorAxialLimit:10,
 rodWidth:20,rodHeight:20,rodWall:1.5,materialE:69000,density:2700,crankWidth:16,crankHeight:8,rodZA:84,rodZB:116,crankZA:64,crankZB:96,
 baseX:0,baseY:0,baseWidth:358,baseHeight:404,baseThickness:8,boxHeight:108,wallThickness:8,frameBraceX:8,paperZ:30,clearance:3,branch:-1,
 // Direct 1:1 drive: motor and output have the same speed and direction.
 // Keep SIMV4-5 motion limits. The half-step datasheet curve cannot prove
 // capacity at these low speeds or with the default 1/16 driver setting.
 maxRPM:8,maxPaperRPM:16,acceleration:1,paperAcceleration:3,maxPenSpeed:120,maxPenAcceleration:150,
 dragForce:2,verticalForce:2,efficiency:.95,frictionAB:.025,frictionC:.03,rotorInertia:0.0000068,couplingInertia:0.000002,penMass:.10,
 penDiameter:10,penMinDiameter:6,penMaxDiameter:12,holderRadius:14,jointRadius:20,jointShaftRadius:10,jointBoreRadius:6.5,
 conditionCaution:10,conditionCritical:100,transmissionCaution:.20,transmissionCritical:.05,parallelStop:.10,workspaceStep:10,testResolution:48,positionTolerance:.5,deflectionLimit:.5,spindleBearingLow:-7,spindleBearingHigh:9,reachAngle:-140});
const cache=new WeakMap();
function normalize(input={}) {
 const c={...DEFAULT_CONFIG,...input};
 // Imported SIMV4-5 configurations keep their motion settings; obsolete gearing
 // parameters cannot introduce a transmission into this direct-drive version.
 for(const k of ['outputTeethA','outputTeethB','outputTeethC','motorTeeth','gearModule','motorDirectionA','motorDirectionB','motorDirectionC','gearInertia'])delete c[k];
 for(const k of Object.keys(DEFAULT_CONFIG))if(!['patternId','wordText'].includes(k)&&!Number.isFinite(c[k]))throw Error('Ongeldige parameter: '+k);
 if(typeof c.wordText!=='string')throw Error('Gebruik 1 tot 8 letters (A–Z).');
 c.wordText=c.wordText.trim().toUpperCase();
 if(!/^[A-Z]{1,8}$/.test(c.wordText))throw Error('Gebruik 1 tot 8 letters (A–Z), zonder spaties of cijfers.');
 if(typeof c.patternId!=='string'||(c.patternId&&window.MotioPatterns&&!window.MotioPatterns.get(c.patternId)))throw Error('Onbekend patroon');
 for(const k of ['radiusA','radiusB','lengthA','lengthB','paperRadius','paperThickness','paperMass','rodWidth','rodHeight','rodWall','materialE','density','efficiency','workspaceStep','baseWidth','baseHeight','baseThickness','boxHeight','wallThickness','penDiameter','couplingRadius','couplingHeight','motorStepAngle','motorCurrent','motorVoltage','motorWidth','motorLength','motorShaftDiameter','motorMountPitch','motorStepsPerFullStep'])if(c[k]<=0)throw Error(k+' moet positief zijn');
 if(c.couplingRadius<=Math.max(6,c.motorShaftDiameter/2)||c.couplingHeight<10)throw Error('Koppeling: boring en voldoende insteeklengte vereist');
 if(![1,2,4,8,16,32].includes(c.motorStepsPerFullStep))throw Error('Microstepping: kies 1, 2, 4, 8, 16 of 32');
 if(c.boxHeight<=2*c.baseThickness||2*c.wallThickness>=Math.min(c.baseWidth,c.baseHeight))throw Error('Ongeldige box- of wandafmetingen');
 if(c.rodWall*2>=Math.min(c.rodWidth,c.rodHeight))throw Error('Kokerwand sluit de doorsnede');
 if(![-1,1].includes(c.branch)||c.clearance<0||c.efficiency>1)throw Error('Ongeldige branch, vrijloop of efficiëntie');
 if(c.penDiameter<c.penMinDiameter||c.penDiameter>c.penMaxDiameter||c.penMaxDiameter>=c.jointBoreRadius*2)throw Error('Pen past niet in doorlopende boring');
 if(c.paperMargin<0||c.paperMargin>=c.paperRadius)throw Error('Ongeldige papiermarge');
 if(c.spindleBearingHigh-c.spindleBearingLow<16)throw Error('Papierspindel: lagerafstand te klein');
 for(const key of ['A','B','C'])if(c.motorCurves?.[key]) {
  const curve=c.motorCurves[key];
  if(!Array.isArray(curve.points)||curve.points.length<2||!curve.source)throw Error('Motorcurve vereist bron en minstens twee [RPM, Nm]-punten');
  curve.points.forEach((p,i)=>{if(!Array.isArray(p)||p.length!==2||p.some(v=>!Number.isFinite(v)||v<0)||(i&&p[0]<=curve.points[i-1][0]))throw Error('Motorcurve: oplopende RPM en niet-negatief koppel vereist');});
 }
 // A frozen snapshot prevents cached geometry drifting away from its configuration.
 for(const k of ['maxRPM','maxPaperRPM','acceleration','paperAcceleration','maxPenSpeed','maxPenAcceleration','positionTolerance','deflectionLimit'])if(c[k]<=0)throw Error(k+' moet positief zijn');
 for(const k of ['dragForce','verticalForce','penMass','rotorInertia','couplingInertia','frictionAB','frictionC'])if(c[k]<0)throw Error(k+' mag niet negatief zijn');
 if(c.workspaceStep<2||c.workspaceStep>50||c.testResolution<8||c.testResolution>180||!Number.isInteger(c.testResolution))throw Error('Workspace stap 2–50 mm; testresolutie 8–180 geheel');
 if(![0,1].includes(c.motorCurveConditionsConfirmed))throw Error('Drivercondities moeten 0 of 1 zijn');
 if(!(0<c.transmissionCritical&&c.transmissionCritical<c.transmissionCaution&&c.transmissionCaution<1&&c.conditionCaution>1&&c.conditionCritical>c.conditionCaution&&c.parallelStop>0&&c.parallelStop<1))throw Error('Ongeldige singulariteitsgrenzen');
 const freeze=o=>{if(o&&typeof o==='object'){Object.values(o).forEach(freeze);Object.freeze(o);}return o;};
 return freeze(structuredClone(c));
}
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

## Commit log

2026-10-01 Bestanden van de box
    [MotioV1.dxf, mPlaat.dxf]
2026-10-01 SIMV3 lancering 1
    [MOTIO-SimV3-BOM.csv]
2026-10-06 sigma boy
    [MOTIO-SimV3-BOM.csv]
2026-10-08 added script for aut render in fusion and dfx files
    [1_doos_met_asgaten.dxf, 2_tandwielen.dxf, 3_armen.dxf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]
2026-10-08 Technische gegevens van motor toegevoegd.
2026-10-08 SIMV4 (In V3)
    [MOTIO-SimV3-BOM.csv, MOTIO-V4-BOM.csv]
2026-10-08 SIMV4 lancering (visueel nu net zoals het prototype)
    [MOTIO-V4-BOM.csv]
2026-10-08 Toevoeging motor basiswerking.
2026-10-11 Uitleg werking motor vervolledigd.
2026-10-15 Aanpassing TestCode -> Gebruik van PWM | Toevoegen hardware schema's rpi5 & gShield
2026-10-19 Add gear train and joint functionality for cycloid motion simulation
    - Implemented gear ratios for motion links in `gear_train.py`.
    - Created `JointMaker` class in `joints.py` to manage revolute joints and rigid groups.
    - Added animation capabilities in `animation.py` to simulate gear movement.
    - Developed `WedgeBuilder` class in `wedge.py` for constructing control-panel wedge components.
    - Introduced `WedgeMount` class in `wedge_mount.py` to define slots for the control-panel wedge.
    - Generated necessary bytecode files for optimized performance.
2026-10-22 Jarno denkt dat hij in een edit zit. (SIMV7 afgewerkt - FINAL SIM)
2026-10-22 Box V3: stappenmotoren van SIMV7 in kast van 4 mm MDF
    Vervangt de tandwielaandrijving van V2 door de drie stappenmotoren,
    krukken, armen en het plateau van Ward's SIMV7. De V2-map blijft ongewijzigd.
    - Lasergenerator: kast met motorgaten, plateau Ø210 van 4 mm, SVG en DXF
    - Fusion-script: statisch model in de thuisstand van SIMV7
    - Kast zo klein mogelijk (343,4 x 304,3 mm) door het mechanisme 56,3° te
    draaien, met Ward's 3 mm vrijloop; ongeveer 24% minder MDF
    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
2026-10-22 Box V3: tussenschot en motorgaten aangepast in generator en Fusion-script
    DXF/SVG voor lasersnijden opnieuw gegenereerd.
2026-10-22 Bedieningspaneel: sleuventest controleert voorwand boven het tussenschot
2026-10-22 README: SIMV7, Box V3, mermaid-diagrammen en BOM; screenshots van SIMV7
2026-10-22 README: BOM aangepast aan Box V3 (4 mm MDF, M3x8-bouten)
2026-10-22 README: Box V3 gebouwd in 4 mm MDF, Fusion-afbeelding toegevoegd
2026-10-29 Startup doc for new Raspberry PI
2026-11-12 Herorganiseer repo naar Hardware, Software, Research en Documentation
    Verplaats Box V3 en de schema's naar Hardware, hernoem de simulator naar
    Software/Simulator, geef bestanden zonder extensie een duidelijke naam en
    zet afbeeldingen naast het document waar ze bij horen.
2026-11-12 Voeg README per map toe en herstel links
    Elke map legt uit wat erin zit, waarom het daar staat en hoe het
    samenhangt, met mermaid-schema's. Links naar verplaatste bestanden zijn
    aangepast.
2026-11-12 Zet afbeeldingen in assets-mappen en voeg kleine documenten samen
    Afbeeldingen staan nu in een assets-map naast hun document. Gegevens en
    aansturing van de motor, gShield-uitleg en -gegevens, scherm- en lagerkeuzes
    en het hardwareschema zijn samengevoegd tot een document per onderwerp.
2026-11-12 Voeg dubbele kastcode samen en herstel paden na verplaatsing
    box_design stond identiek in het Fusion-script en in de generator en staat
    nu eenmaal in Hardware/BoxV3/box_design. De paden in wedge_placement en in
    de afstemmingstest van het bedieningspaneel wezen nog naar Research/concept
    en zijn hersteld. De 3 stappenmotoren staan nu correct in de motornotities.
